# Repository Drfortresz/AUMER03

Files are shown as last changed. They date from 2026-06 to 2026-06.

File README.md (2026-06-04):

<div align="center">
<p align="center">
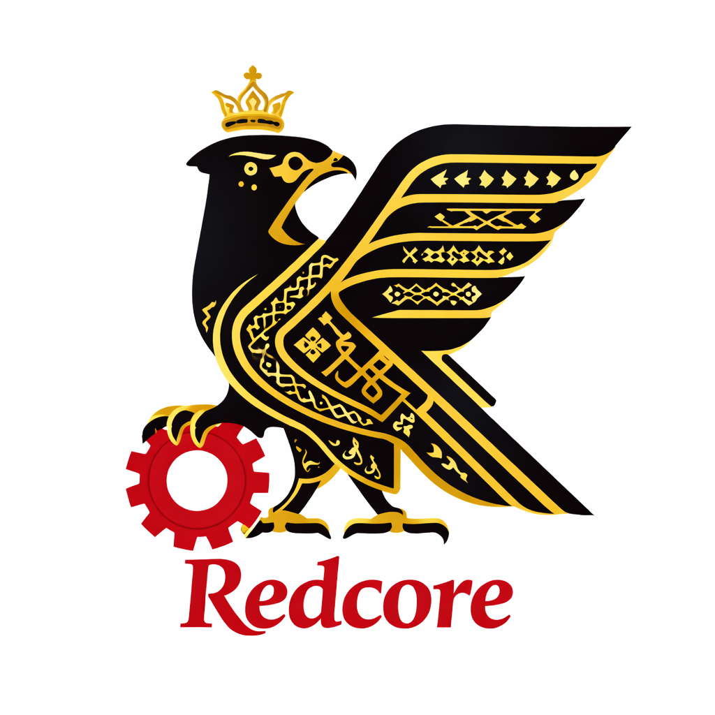
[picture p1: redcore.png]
Redcore Logo
  
</p>

# 🐦‍🔥redcores - future engineers🐦‍🔥

**Kuwait National Qualifier · May 31, 2026**






</div>

---

## 📋 Table of Contents

- [🧩 Project Overview](#-project-overview)
- [📁 Repository Structure](#-repository-structure)
- [🔩 Hardware & Components](#-hardware--components)
- [⚡ Power & Electrical System](#-power--electrical-system)
- [💻 Software Description](#-software-description)
- [🚗 Mobility, Power & Sensing System](#-mobility-power--sensing-system)
- [👁️ Obstacle Management & Vision System](#️-obstacle-management--vision-system)
- [🧱 3D Model](#-3d-model)
- [📸 Robot Photos](#-robot-photos)
- [🧪 Testing & Calibration](#-testing--calibration)
- [😎 team in action](#-team-in-action)
- [📈 Results & Performance](#-results--performance)
- [🎬 Video Demonstrations](#-video-demonstrations)
- [👨‍💻 Team Members](#-team-members)

---

## 🧩 Project Overview

The redcore initiative showcases a self-driving vehicle engineered to complete three autonomous laps on a closed course marked with randomized traffic signs. The design blends mechanical engineering, embedded electronics, and computer vision to deliver smooth driving, adaptive decision-making, and intelligent obstacle handling.

At its core, the robot is organized into four interconnected subsystems:

**🌊Motion System**  
A sturdy chassis powered by a DC motor for propulsion and a servo motor for steering. Real-time sensor feedback ensures precise control through curves and speed changes.

**⚡Energy System**  
A 7.4V Li-Po battery provides reliable power to both motors and control electronics. The Xmotion board regulates distribution, reducing electrical noise and maintaining consistent performance.

**🕵️Detection System**  
Three ultrasonic sensors continuously measure distances to walls and obstacles, keeping the robot centered. A PixyCam vision sensor identifies red and green traffic markers to guide directional choices.

**🧠Smart Obstacle Handling**  
By fusing ultrasonic data with PixyCam vision, the robot interprets traffic signs, maintains lane balance, avoids collisions, and completes its run by autonomously parking in the designated zone.

Together, these subsystems demonstrate a holistic approach to autonomous mobility, combining dependable sensing, efficient power management, and intelligent control strategies to operate safely in dynamic environments.

---

## 📁 Repository Structure

```
WRO-Future-Engineers-2026/
├── README.md
├── src/
│   ├── Open_Challenge/
│   │   └── Open_Challenge.ino       ← PD wall-following controller
│   └── Obstacle_Challenge/
│       └── Obstacle_Challenge.ino   ← PD + Pixy2 obstacle avoidance
├── Vehicle_Photos/                   ← 6-angle robot photography
├── Models/                           ← 3D design files (.3mf)
├── Schemes/                          ← Electrical schematic & wiring
├── videos/                           ← Demo video links
└── docs/                             ← Team logo & assets
```

---

## 🔩 Hardware & Components

| Component | Model / Spec | Purpose |
|---|---|---|
| Microcontroller | Arduino Uno (ATmega328P, 16MHz) | Main logic, sensor reading & control |
| Motor Driver | Cytron MD13S | DC motor speed & direction control |
| Drive Motor | Brushed DC 7.4V | Rear-wheel propulsion (RWD) |
| Steering Servo | Standard servo motor | Front Ackermann steering |
| Distance Sensors | 2× HC-SR04 ultrasonic | Left/right wall distance measurement |
| Vision Sensor | Pixy2 Camera (SPI) | Red/green pillar color detection |
| Battery | 7.4V LiPo 2S | Main power supply for all systems |
| Chassis | WLtoys 284010 (1:28 RC scale) | Compact, robust, competition-ready platform |

**Physical Specs:**  
📐 Dimensions: ~17 × 9 × 7 cm — within WRO 30×20×30 cm limit ✅  
⚖️ Mass: ~0.5 kg (without electronics) — within 1.5 kg limit ✅

<div align="center">
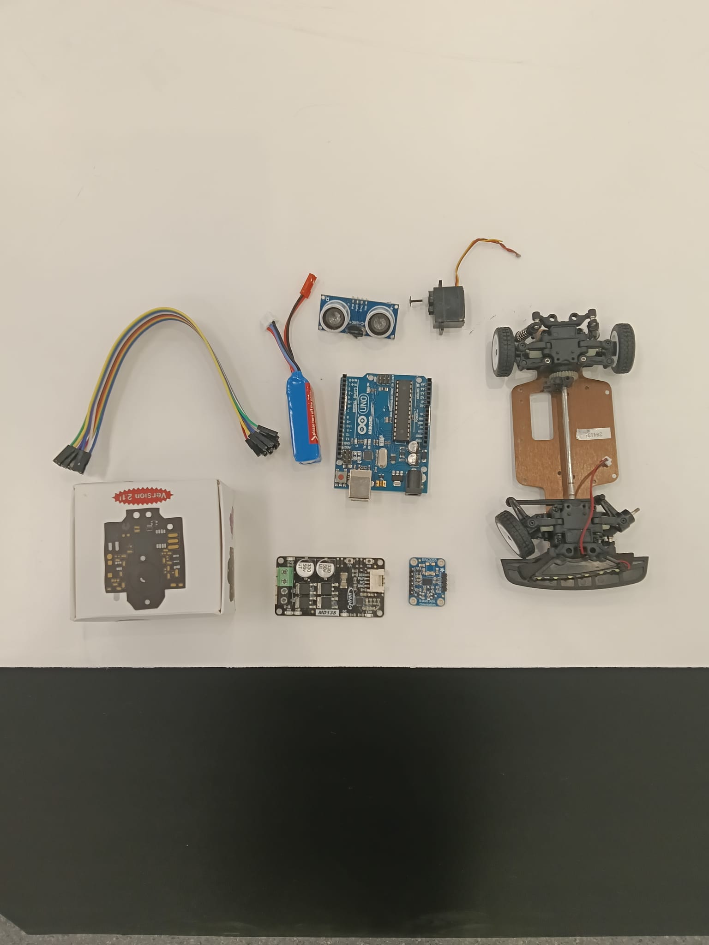
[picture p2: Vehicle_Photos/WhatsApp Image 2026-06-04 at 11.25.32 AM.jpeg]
Robot Components

<br/><sub><i>Robot components layout</i></sub>
</div>

---

## ⚡ Power & Electrical System

```
LiPo 7.4V ──→ Cytron MD13S  (motor power)
          └──→ Arduino Vin   (logic power)
                  └──→ 5V pin ──→ Servo + HC-SR04 (×2) + Pixy2
```

**Wiring Summary:**

| Component | Pin Connection |
|---|---|
| HC-SR04 Left | TRIG → D4 · ECHO → D5 · VCC → 5V |
| HC-SR04 Right | TRIG → D2 · ECHO → D9 · VCC → 5V |
| Servo | SIG → A0 · VCC → 5V |
| Cytron MD13S | PWM → D3 · DIR → D8 |
| Pixy2 (SPI) | CS → D10 · MOSI → D11 · MISO → D12 · SCK → D13 |

<div align="center">
Lab Tools
<br/><sub><i>Tools and equipment used in development</i></sub>
</div>

---

## 💻 Software Description

The Arduino Uno is programmed using **Arduino IDE** with code written in C/C++. The code architecture is divided into two main modules:

- **`Open_Challenge.ino`** — PD wall-following controller with anti-zigzag techniques
- **`Obstacle_Challenge.ino`** — PD wall-following + Pixy2 vision mode switching

Both sketches share the same core PD logic and tuned parameters, with the Obstacle Challenge adding a hysteresis-based mode manager for pillar detection.

### Control Flow Diagram

```
[HC-SR04 L/R] ──→ [3× Average + LPF] ──→ ┐
                                           ├──→ [Mode Manager] ──→ [PD / Pixy2] ──→ [Servo A0]
[Pixy2 Camera] ──→ [Area + X Filter]  ──→ ┘                                              │
                                                                                           ↓
                                                                                  [Cytron MD13S]
                                                                                           │
                                                                                      [DC Motor]
```

### Tuned Parameters

| Parameter | Value | Role |
|---|---|---|
| `KP` | 0.10 | Proportional gain |
| `KD` | 0.09 | Derivative gain |
| `MOTOR_SPEED` | 55 | Normal cruising PWM |
| `TURN_SPEED` | 45 | Reduced PWM on sharp turns |
| `CENTER_ANGLE` | 90° | Servo straight-ahead |
| `ERROR_DEADBAND` | 0.8 cm | Noise suppression threshold |
| `DERIV_ALPHA` | 0.45 | Derivative low-pass filter |
| `SERVO_ALPHA` | 0.55 | Servo output smoother |
| `MAX_VALID_CM` | 75 cm | Corner spike clamp value |
| `HARD_TURN_DEG` | 28° | Speed-reduction trigger |

---

## 🚗 Mobility, Power & Sensing System

The robot's mobility relies on a single DC motor controlled through the **Cytron MD13S** driver, providing smooth forward motion. A **7.4V LiPo battery** powers all components efficiently through the Arduino's onboard regulator.

**Wall-following PD Controller:**

```
error      = leftDist − rightDist
derivative = smoothed(error − lastError)
output     = KP × error + KD × derivative
servoAngle = CENTER_ANGLE + output
```

**Anti-zigzag techniques applied:**
- **Error deadband** (±0.8 cm): ignores sensor noise below threshold
- **Derivative low-pass filter** (α=0.45): prevents jitter from spike readings
- **Servo output smoothing** (α=0.55): eliminates mechanical oscillation
- **Corner spike clamping** (max 75 cm): ignores false corner wall readings
- **Adaptive speed**: automatically slows down on turns >28° from center
- **Sensor fallback**: if one ultrasonic fails, mirrors the other side

---

## 👁️ Obstacle Management & Vision System

The Pixy2 camera identifies red and green pillars using color signatures trained under WRO arena lighting:

| Pillar | Signature | Rule | Steering Action |
|---|---|---|---|
| 🟢 Green | Sig 1 | Pass on LEFT of pillar | Steer LEFT (angle > 90°) |
| 🔴 Red | Sig 2 | Pass on RIGHT of pillar | Steer RIGHT (angle < 90°) |

**Steering angles by pillar position (X coordinate on camera):**

| Color | X < 120 | X 120–170 | X > 170 |
|---|---|---|---|
| 🟢 Green | Hard Left (135°) | Med Left (120°) | Soft Left (105°) |
| 🔴 Red | Soft Right (75°) | Med Right (60°) | Hard Right (45°) |

**Mode switching hysteresis:**
- Enters `PIXY MODE` after **2 consecutive** valid detections
- Returns to `PID MODE` after **3 consecutive** misses
- Minimum hold time **280 ms** — prevents rapid flickering
- Slew-rate limit **6°/step** — ensures smooth servo transitions
- Detection filters: minimum area 200 px², X range 20–300 px

---

## 🧱 3D Model

The robot chassis is based on the WLtoys 284010 (1:28 scale RC car), modified with 3D-printed mounts for electronics and sensors.

<div align="center">
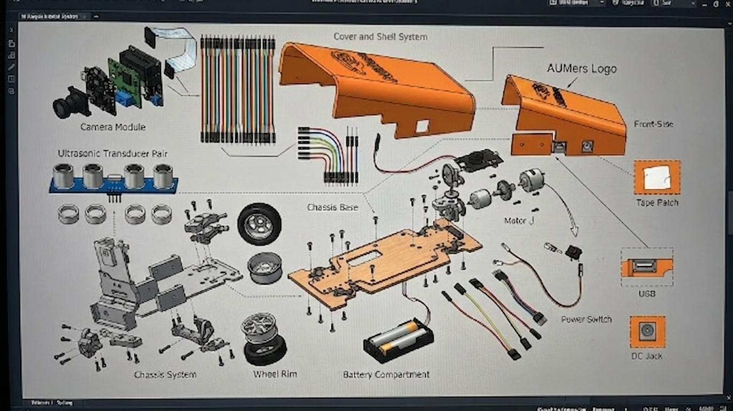
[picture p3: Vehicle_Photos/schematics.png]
3D Model

<br/><sub><i>3D printed design — electronics tray and sensor mounts</i></sub>
</div>

3D files available in [`Models/`](Models/)

---

## 📸 Robot Photos

<div align="center">
<table>
  <tr>
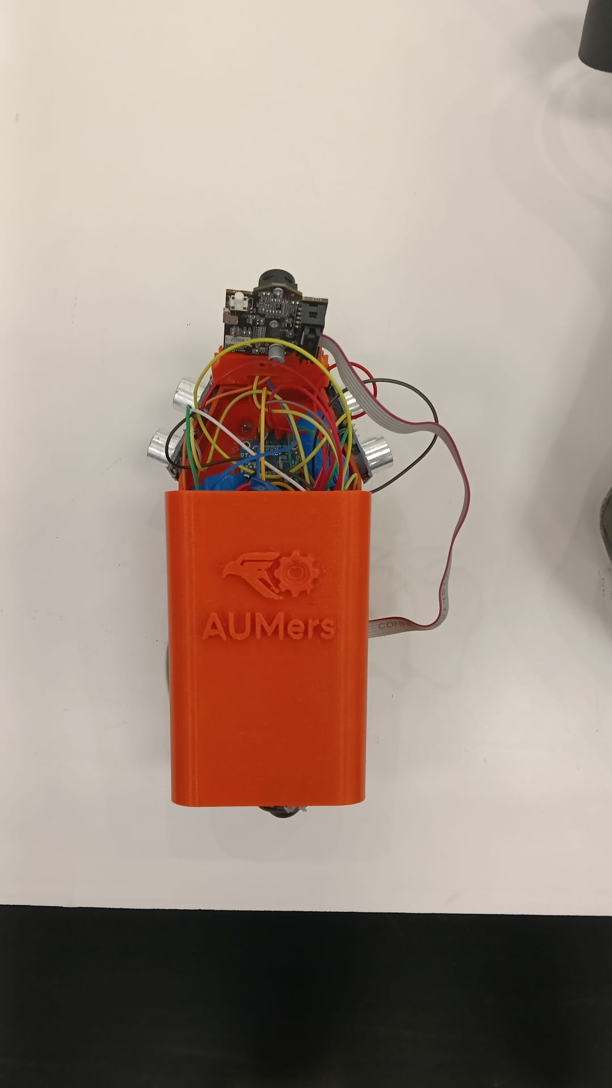
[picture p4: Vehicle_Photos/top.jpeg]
    <td align="center"><br/><sub><b>top</b></sub></td>
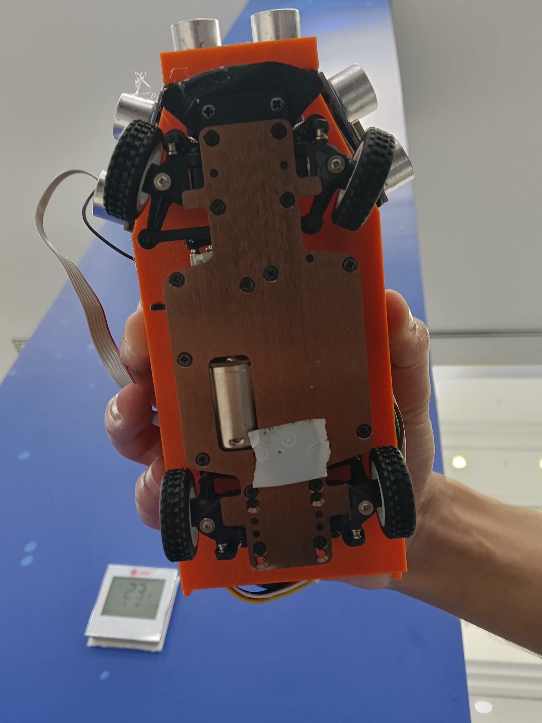
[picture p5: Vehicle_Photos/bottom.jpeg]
    <td align="center"><br/><sub><b>bottom</b></sub></td>
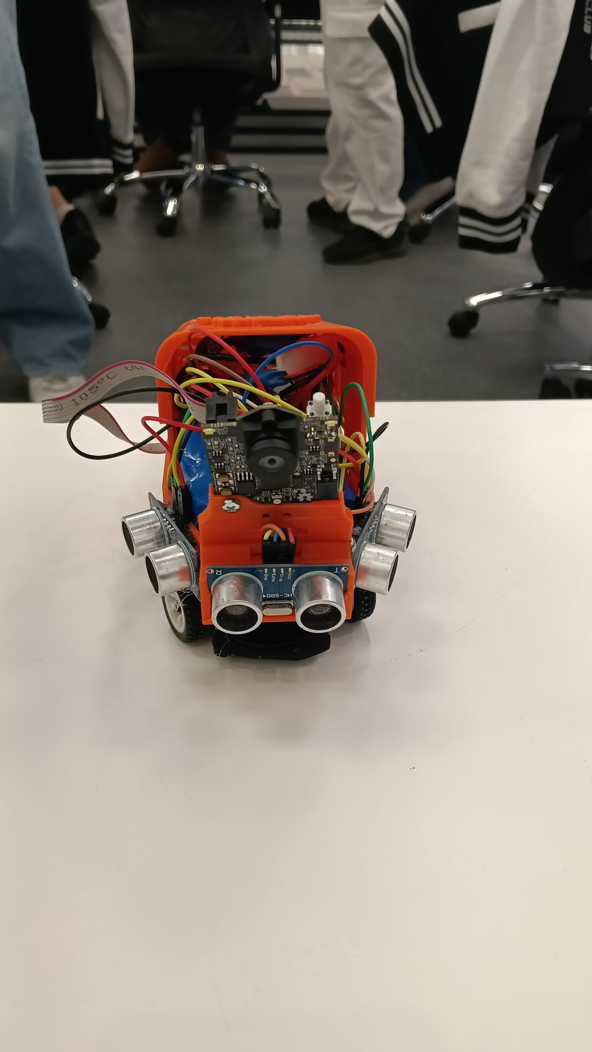
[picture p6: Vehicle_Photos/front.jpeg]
    <td align="center"><br/><sub><b>front</b></sub></td>
  </tr>
  <tr>
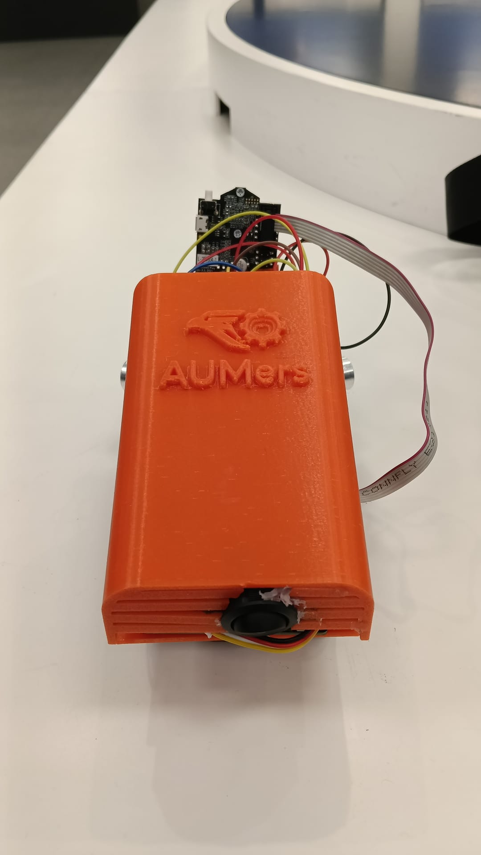
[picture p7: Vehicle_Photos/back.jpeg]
    <td align="center"><br/><sub><b>back</b></sub></td>
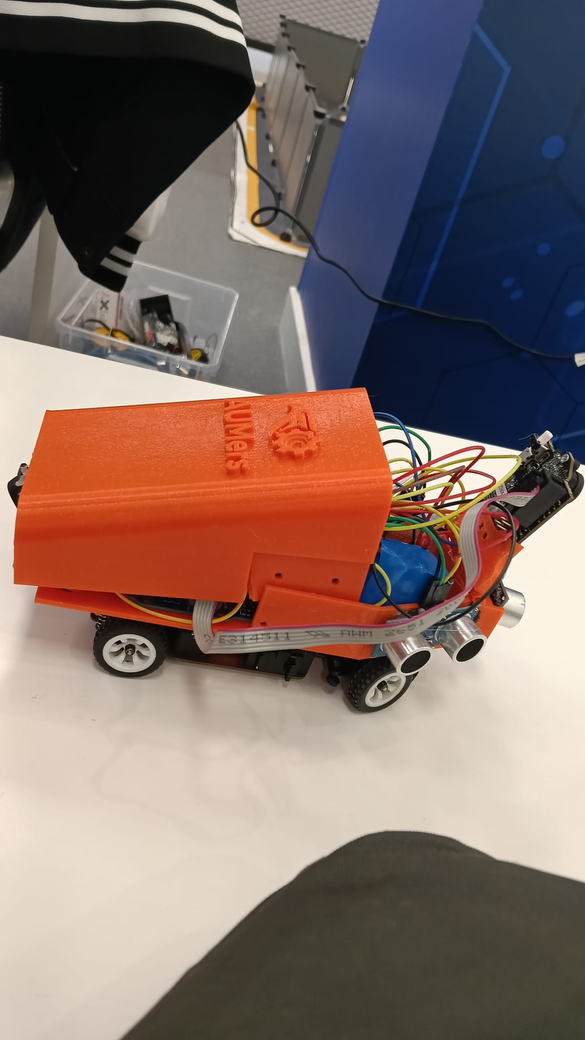
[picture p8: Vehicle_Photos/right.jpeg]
    <td align="center"><br/><sub><b>right</b></sub></td>
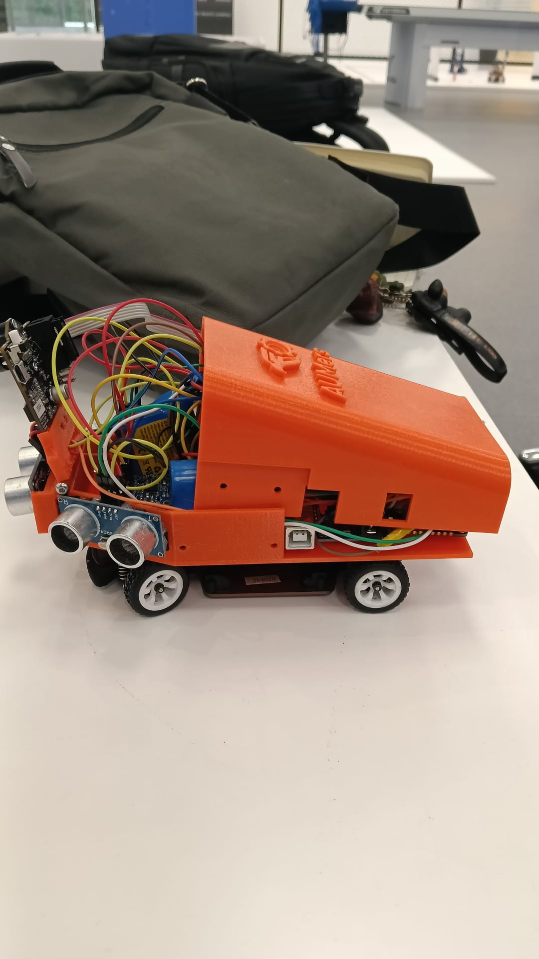
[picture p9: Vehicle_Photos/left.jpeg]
    <td align="center"><br/><sub><b>left</b></sub></td>
  </tr>
</table>
</div>

---

## 😎 team in action

<div align="center">
<div align="center">
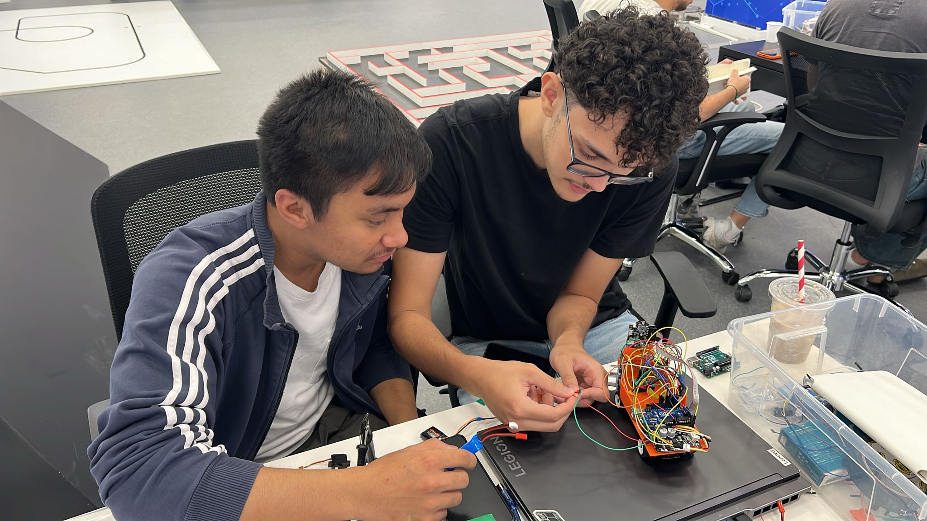
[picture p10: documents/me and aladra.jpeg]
  
</div>
<div align="center">
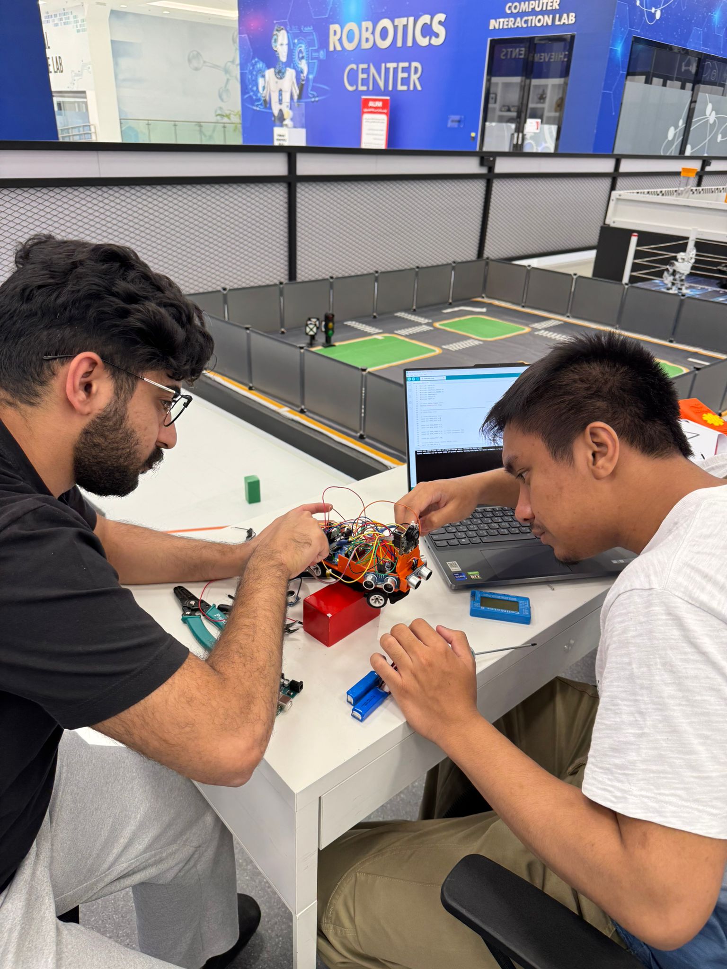
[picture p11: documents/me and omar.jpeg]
  
</div>
<div align="center">
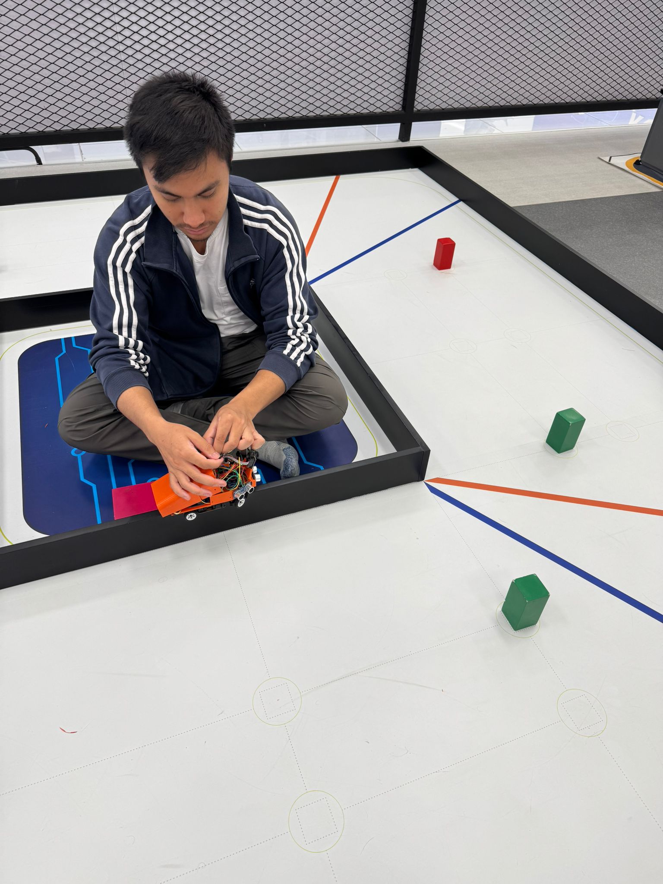
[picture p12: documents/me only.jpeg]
  
</div>

---

## 🧪 Testing & Calibration  

| Test | Purpose / Outcome |
|---|---|
| Ultrasonic Calibration | Verified accuracy against wall distances; tuned `MAX_VALID_CM` |
| Servo Center Calibration | Determined true `CENTER_ANGLE` for straight-line driving |
| Motor Dead Zone Test | Identified minimum effective PWM value |
| PD Controller Tuning | Iteratively adjusted `KP`/`KD` for smooth wall-following |
| Pixy2 Color Training | Trained red & green signatures under arena lighting |
| Anti-Zigzag Validation | Fine-tuned `DERIV_ALPHA` and `SERVO_ALPHA` to eliminate oscillation |
| Three-Lap Validation | Confirmed successful completion of Open Challenge |
| Obstacle Avoidance Trials| Tested all pillar color/position combinations for robust navigation |

## 📈 Results & Performance

| Task | Performance |
|---|---|
| Track navigation — 3 laps | Completed successfully in consistent times ✅ |
| Wall-following accuracy | < 2 cm center deviation on straight segments ✅ |
| Traffic pillar recognition | >95% accuracy under arena lighting conditions ✅ |
| Obstacle avoidance | Smooth navigation, no collisions ✅ |
| Mode switching | Clean PID↔Pixy transitions with no oscillation ✅ |

---

## 📽️ Video Demonstrations

| Challenge | Description | File |
|---|---|---|
| Open Challenge | 3-lap autonomous wall-following | [`videos/Open_Challenge.mp4`](https://github.com/Drfortresz/AUMER03/blob/main/Videos/open%20challenge.mp4) |
| Obstacle Challenge | Full pillar detection + avoidance | [`videos/Obstacle_Challenge.mp4`](https://github.com/Drfortresz/AUMER03/blob/main/Videos/obstical.mp4) |

---

## 👷 Team

<div align="center">

| Member | Focus Area | Key Responsibilities |
|---|---|---|
| **Mohammad Abdul Hakim A I** | Software & Coding | Writing control code · System logic |
| **Mohammad Omar Mohammad** | Hardware & Building | Mechanical design · Assembly & integration |
| **Mohamed Amine Ladraa** | Vision & Testing | Camera vision · Calibration & performance checks |

| ✨very professsional coach✨ |
|---------------------|
| Mohammad sharsheer |

</div>

---

<div align="center">

**🐦‍🔥redcores🐦‍🔥**

*Kuwait · WRO Future Engineers 2026*

</div>

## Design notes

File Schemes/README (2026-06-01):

# ⚡ Electrical Schematic — redcores

📄 **[Schematic_Wiring_Diagram.pdf](Schematic_Wiring_Diagram.pdf)** — Full Fritzing wiring diagram

## Wiring Summary

| Component | Pin(s) | Notes |
|---|---|---|
| HC-SR04 Left | TRIG→D4, ECHO→D5 | 5V powered |
| HC-SR04 Right | TRIG→D2, ECHO→D9 | 5V powered |
| Servo | SIG→A0 | 5V powered |
| Cytron MD13S | PWM→D3, DIR→D8 | Motor driver |
| Pixy2 | CS→D10, MOSI→D11, MISO→D12, SCK→D13 | SPI, 5V powered |

## Power Distribution

```
LiPo 7.4V ──→ Cytron MD13S  (motor power)
          └──→ 5V Buck Converter ──→ Arduino Vin
                                        └──→ Servo / Ultrasonics / Pixy2
```

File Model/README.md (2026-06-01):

# 🧱 3D Models — Blue Wave Team

Contains 3D design files for the robot's mechanical structure and sensor mounts.

| File | Description |
|---|---|
| `main_body.3mf` | Main chassis and electronics tray |

**Software:** Tinkercad / Fusion 360  
**Material:** PLA — 20% infill, 0.2 mm layer height.

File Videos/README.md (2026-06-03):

# 🎬 Video Demonstrations — redcores

| Challenge | File | Description |
|---|---|---|
| Open Challenge | `https://github.com/Drfortresz/AUMER03/blob/main/Videos/open%20challenge.mp4` | 3-lap autonomous wall-following run |
| Obstacle Challenge | `https://github.com/Drfortresz/AUMER03/blob/main/Videos/obstical.mp4` | Full obstacle avoidance run |

> Add your `.mp4` files here or paste YouTube links below.

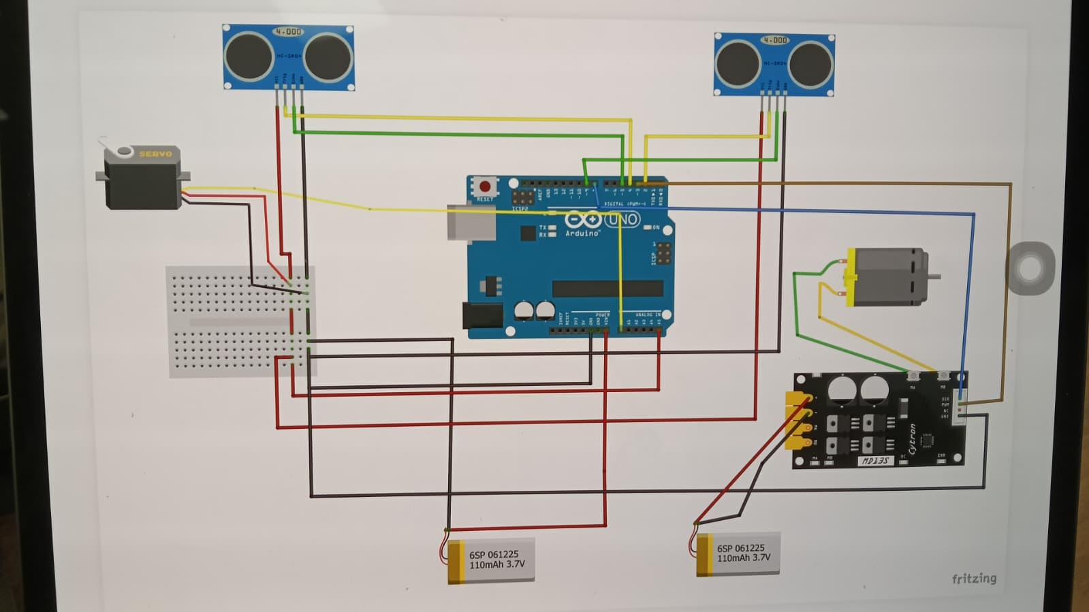
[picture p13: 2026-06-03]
Schemes/schematics.jpeg

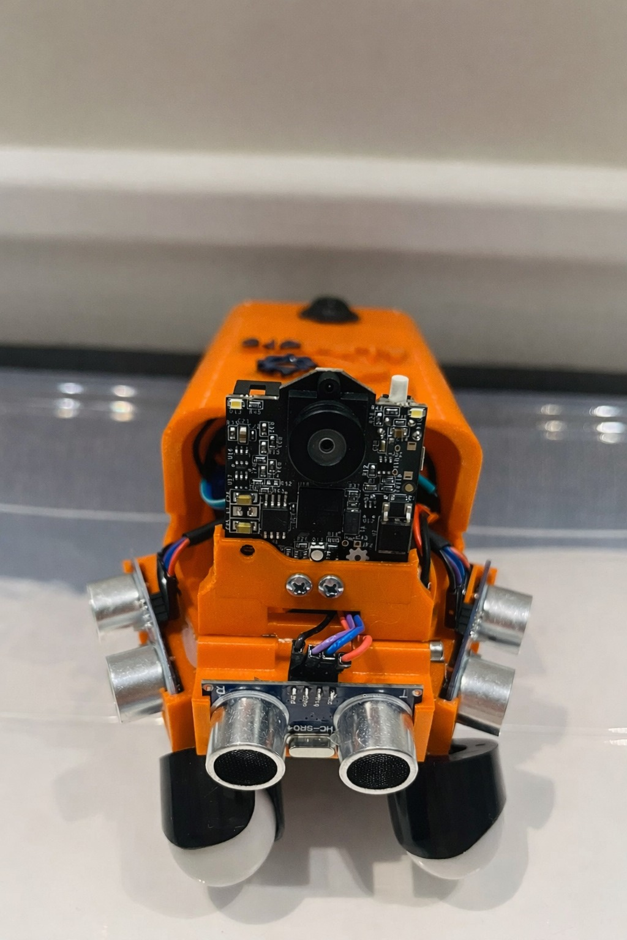
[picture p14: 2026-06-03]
Vehicle_Photos/robot front.png

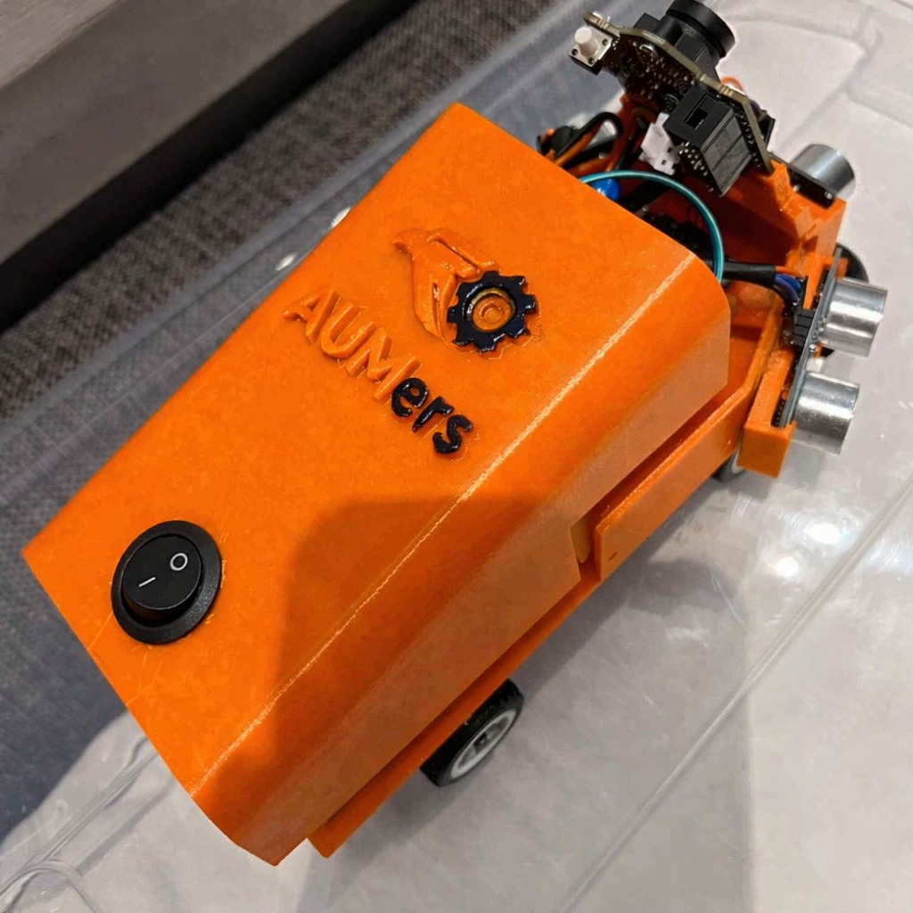
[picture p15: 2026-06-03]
Vehicle_Photos/robot tilted back.png

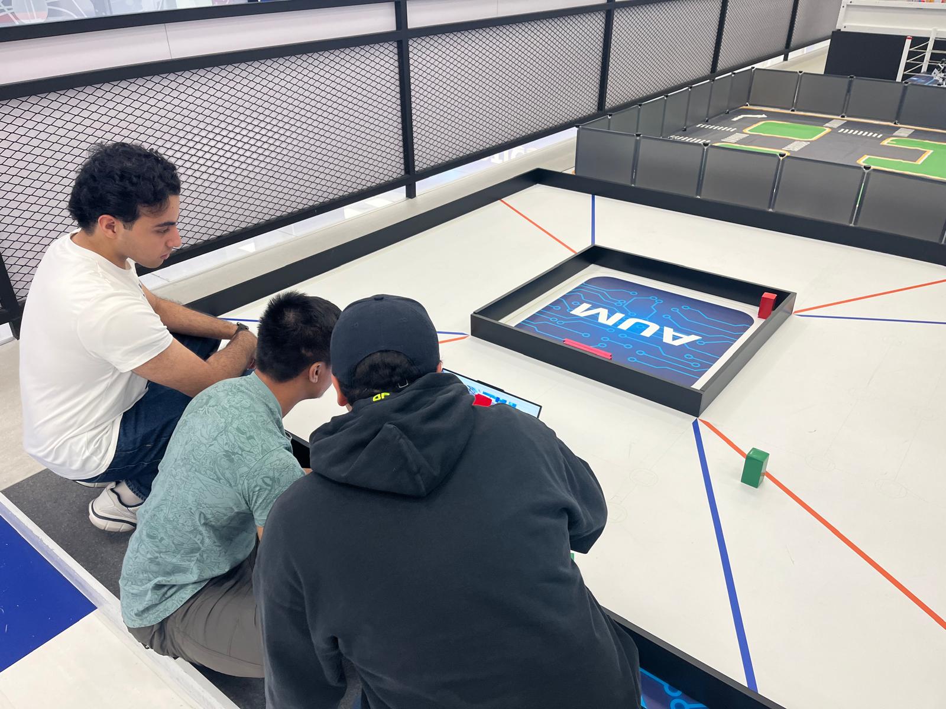
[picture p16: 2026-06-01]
documents/team_action_1.jpg

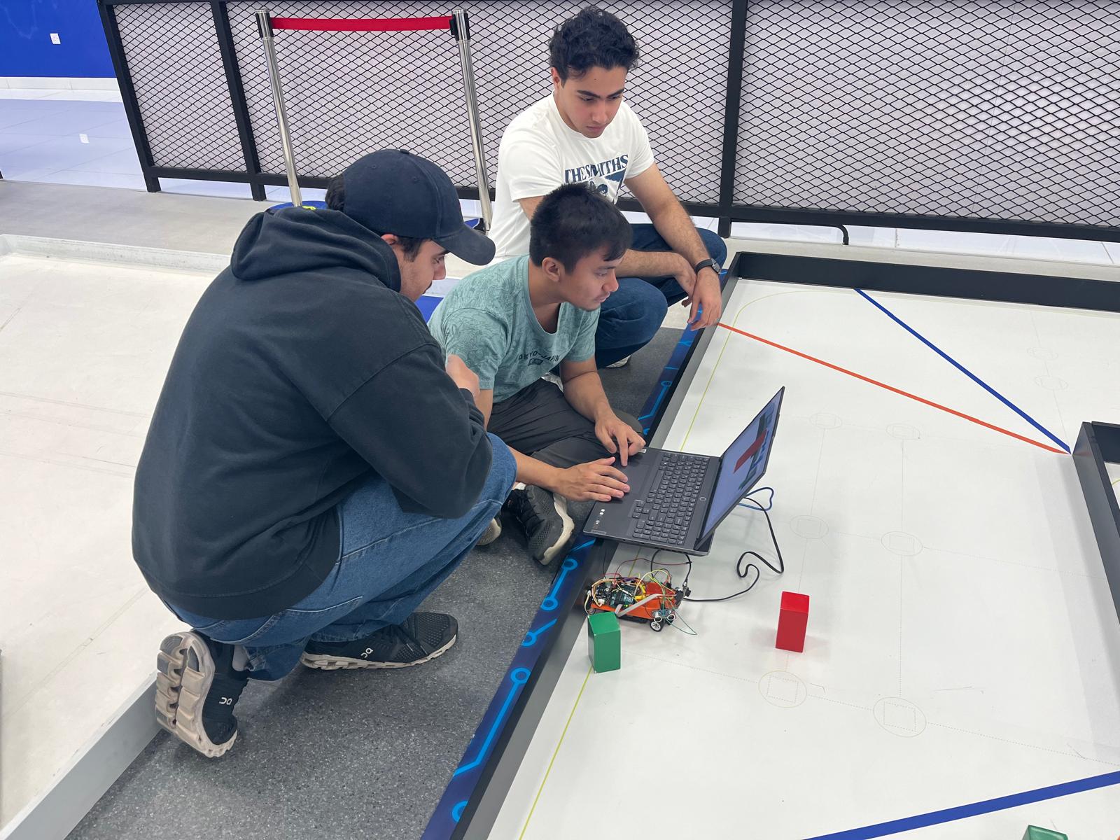
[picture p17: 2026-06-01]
documents/team_action_3.jpg

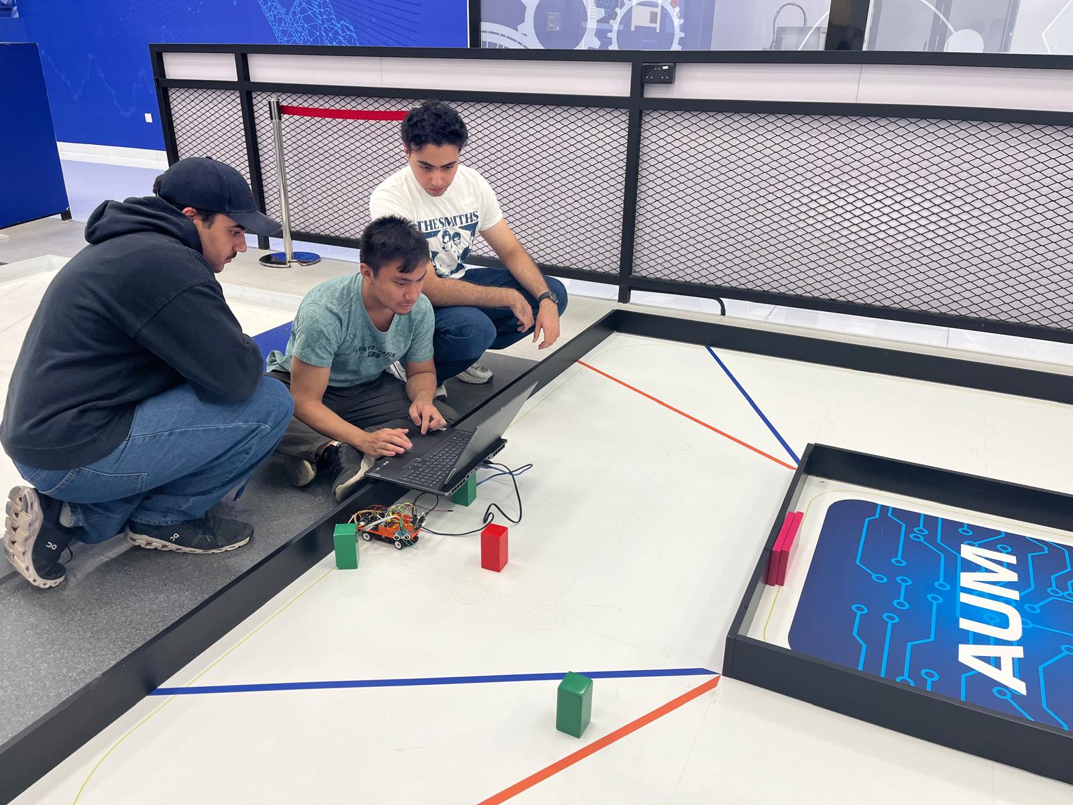
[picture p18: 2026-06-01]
documents/team_action_2.jpg

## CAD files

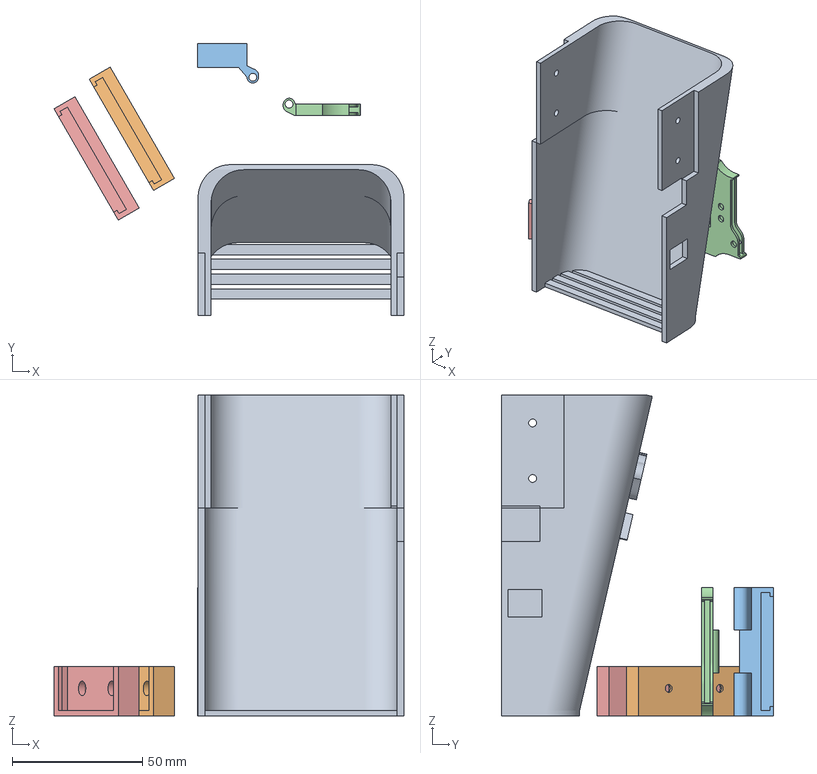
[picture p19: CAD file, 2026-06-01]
Model/WRO_redcore_main_body_3D_Desgin v2.3mf
134.3 x 104.5 x 123.0 mm
wro main body v2.step
us bracket wro v2.step x 2
us brackeetXpixy v2.step
pixy bracket wro.step

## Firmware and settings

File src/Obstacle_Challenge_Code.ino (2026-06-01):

#include <Servo.h>
#include <Wire.h>
#include <Adafruit_Sensor.h>
#include <Adafruit_BNO055.h>
#include <NewPing.h>
#include <Pixy2.h>
#include <math.h>

// ===== Debug Toggle =====
#define DEBUG_OUTPUT true
// ===========================================================================

// ===== Pins =====
// ===== Ultrasonic =====
const int TRIG_LEFT  = 4;
const int ECHO_LEFT  = 5;
const int TRIG_RIGHT = 2;
const int ECHO_RIGHT = 9;
const int TRIG_FRONT = 11;
const int ECHO_FRONT = 12;

const int SERVO_PIN  = 10;

// ===== Motor Driver (Cytron MD13S) =====
const int PWM_PIN = 3;   
const int DIR_PIN = 8;   
// ===========================================================================

// ===== Speed Settings =====
const int MOTOR_SPEED = 50;
const int MOTOR_SPEED_STOP = 0;
const int FRONT_STOP_CM = 20;

// ===== PID Settings =====
const float KP = 0.6;
const float KD = 0.2;
const float KI = 0.0;

float lastError = 0;
float eintegral = 0;
const float I_MAX = 80.0;

// ===== Steering Angles =====
const int CENTER_ANGLE = 90;
const int MIN_SERVO_ANGLE = 10;
const int MAX_SERVO_ANGLE = 170;

// ===== BNO055 =====
Adafruit_BNO055 bno = Adafruit_BNO055(55);
float yaw = 0;
float prevYaw = 0;
float totalRotation = 0;
int   laps = 0;

// ===== Ultrasonic =====
#define MAX_DISTANCE 400
NewPing sonarLeft(TRIG_LEFT, ECHO_LEFT, MAX_DISTANCE);
NewPing sonarRight(TRIG_RIGHT, ECHO_RIGHT, MAX_DISTANCE);
NewPing sonarFront(TRIG_FRONT, ECHO_FRONT, MAX_DISTANCE);

// ===== Pixy2 =====
Pixy2 pixy;

const int GREEN_SOFT_LEFT = 105;
const int GREEN_MED_LEFT  = 120;
const int GREEN_HARD_LEFT = 135;
const int RED_SOFT_RIGHT  = 75;
const int RED_MED_RIGHT   = 60;
const int RED_HARD_RIGHT  = 45;

enum ControlMode { MODE_PID, MODE_PIXY };
ControlMode mode = MODE_PID;
unsigned long modeChangedAt = 0;

const uint16_t ENTER_PIXY_FRAMES     = 2;
const uint16_t EXIT_PIXY_MISS_FRAMES = 3;
const unsigned long MODE_MIN_HOLD_MS = 280;

uint16_t pixySeenFrames = 0, pixyMissFrames = 0;
const int PIXY_MIN_AREA = 200;
const int PIXY_MIN_X = 20, PIXY_MAX_X = 300;

float servoCurrentAngle = CENTER_ANGLE;
const float SERVO_SLEW_DEG_PER_STEP = 6.0;

bool  lpfInit = false;
float lpfLeft = 0, lpfRight = 0;
const float ALPHA = 0.9;

Servo steeringServo;
// ===========================================================================

void setup() {
  pinMode(PWM_PIN, OUTPUT);
  pinMode(DIR_PIN, OUTPUT);
  digitalWrite(DIR_PIN, HIGH);

  steeringServo.attach(SERVO_PIN);
  steeringServo.write(CENTER_ANGLE);
  servoCurrentAngle = CENTER_ANGLE;

  Serial.begin(115200);
  Wire.begin();

  if (!bno.begin()) {
    Serial.println("⚠ BNO055 not detected. Check wiring!");
    while (1);
  }
  delay(1000);
  bno.setExtCrystalUse(true);

  pixy.init();

  if (DEBUG_OUTPUT) {
    Serial.println("=== FAST PID + Managed Pixy Switching ===");
    Serial.println("L(cm)\tR(cm)\tF(cm)\tErr\tServo\tYaw\tLaps\tMode");
  }
}

// ===========================================================================

void loop() {

  float leftDist  = getStableDistance(sonarLeft);
  float rightDist = getStableDistance(sonarRight);
  float frontDist = getStableDistance(sonarFront);

  if (frontDist > 0 && frontDist <= FRONT_STOP_CM) {
    runMotor(MOTOR_SPEED_STOP, false);
    Serial.println("⛔ عائق أمامي — توقف مؤقت");
    delay(150);
    return;
  }

  if (leftDist < 0 && rightDist >= 0)  leftDist = rightDist;
  if (rightDist < 0 && leftDist  >= 0) rightDist = leftDist;

  if (leftDist < 0 && rightDist < 0) {
    runMotor(MOTOR_SPEED_STOP, false);
    if (DEBUG_OUTPUT) Serial.println("Both sensors failed — stopping");
    delay(100);
    return;
  }

  if (!lpfInit) {
    lpfLeft = leftDist; 
    lpfRight = rightDist; 
    lpfInit = true;
  } 
  else {
    if (leftDist  > 0) lpfLeft  = ALPHA * leftDist  + (1 - ALPHA) * lpfLeft;
    if (rightDist > 0) lpfRight = ALPHA * rightDist + (1 - ALPHA) * lpfRight;
  }

  sensors_event_t orientationData;
  bno.getEvent(&orientationData, Adafruit_BNO055::VECTOR_EULER);
  yaw = orientationData.orientation.x;

  lapsCount();

  if (laps >= 3) {
    runMotor(MOTOR_SPEED_STOP, false);
    Serial.println("🏁 3 laps done!");
    return;
  }

  // --------- Pixy Confidence ----------

  int blocks = pixy.ccc.getBlocks();
  bool pixyGood = false;
  int  targetPixyAngle = CENTER_ANGLE;

  if (blocks > 0) {

    auto &blk = pixy.ccc.blocks[0];
    int sig   = blk.m_signature;
    int x     = blk.m_x;
    int w     = blk.m_width;
    int h     = blk.m_height;
    int area  = w * h;

    if (DEBUG_OUTPUT) {
      Serial.print("DBG: sig="); Serial.print(sig);
      Serial.print(" x="); Serial.print(x);
      Serial.print(" w="); Serial.print(w);
      Serial.print(" h="); Serial.print(h);
      Serial.print(" area="); Serial.println(area);
    }

    if (area >= PIXY_MIN_AREA && x >= PIXY_MIN_X && x <= PIXY_MAX_X) {
      pixyGood = true;

      if (sig == 1) {
        if (x < 120)      targetPixyAngle = GREEN_HARD_LEFT;
        else if (x < 170) targetPixyAngle = GREEN_MED_LEFT;
        else              targetPixyAngle = GREEN_SOFT_LEFT;
      }
      else if (sig == 2) {
        if (x > 200)      targetPixyAngle = RED_HARD_RIGHT;
        else if (x > 150) targetPixyAngle = RED_MED_RIGHT;
        else              targetPixyAngle = RED_SOFT_RIGHT;
      }
      else {
        pixyGood = false;
      }
    }
  }

  // --------- Pixy Mode Manager ----------

  unsigned long t = millis();

  if (pixyGood) {
    pixySeenFrames++;
    pixyMissFrames = 0;

    if (mode == MODE_PID && pixySeenFrames >= ENTER_PIXY_FRAMES &&
        t - modeChangedAt >= MODE_MIN_HOLD_MS) 
    {
      mode = MODE_PIXY;
      modeChangedAt = t;
      if (DEBUG_OUTPUT) Serial.println(">>> ENTER PIXY MODE");
    }
  }
  else {
    pixyMissFrames++;
    pixySeenFrames = 0;

    if (mode == MODE_PIXY && pixyMissFrames >= EXIT_PIXY_MISS_FRAMES &&
        t - modeChangedAt >= MODE_MIN_HOLD_MS)
    {
      mode = MODE_PID;
      modeChangedAt = t;
      if (DEBUG_OUTPUT) Serial.println("<<< EXIT PIXY MODE");
    }
  }

  // --------- Apply Control ----------

  int servoAngle = CENTER_ANGLE;

  if (mode == MODE_PIXY && pixyGood) {
    servoCurrentAngle += constrain(targetPixyAngle - servoCurrentAngle,
                                   -SERVO_SLEW_DEG_PER_STEP,
                                    SERVO_SLEW_DEG_PER_STEP);

    servoAngle = servoCurrentAngle;
  }
  else {
    float error = lpfLeft - lpfRight;

    eintegral += error;
    eintegral = constrain(eintegral, -I_MAX, I_MAX);

    float derivative = error - lastError;
    lastError = error;

    float output = KP * error + KI * eintegral + KD * derivative;
    servoAngle = CENTER_ANGLE + output;
  }

  servoAngle = constrain(servoAngle, MIN_SERVO_ANGLE, MAX_SERVO_ANGLE);
  steeringServo.write(servoAngle);

  runMotor(MOTOR_SPEED, true);

  if (DEBUG_OUTPUT) {
    Serial.print(lpfLeft); Serial.print("\t");
    Serial.print(lpfRight); Serial.print("\t");
    Serial.print(frontDist); Serial.print("\t");
    Serial.print(lastError); Serial.print("\t");
    Serial.print(servoAngle); Serial.print("\t");
    Serial.print(yaw); Serial.print("\t");
    Serial.print(laps); Serial.print("\t");
    Serial.println(mode == MODE_PID ? "PID" : "PIXY");
  }
}

// ===========================================================================
// ========================= FUNCTIONS =======================================
// ===========================================================================

float getStableDistance(NewPing &sonar) {
  delay(3);
  int d = sonar.ping_cm();
  if (d == 0 || d > MAX_DISTANCE) return -1;
  return d;
}

void runMotor(int speed, bool forward) {
  digitalWrite(DIR_PIN, forward ? HIGH : LOW);
  analogWrite(PWM_PIN, speed);
}

void lapsCount() {
  float delta = yaw - prevYaw;
  if (delta > 180)  delta -= 360;
  if (delta < -180) delta += 360;

  totalRotation += delta;
  prevYaw = yaw;

  if (fabs(totalRotation) >= 360.0) {
    laps++;
    totalRotation = 0;
  }
}

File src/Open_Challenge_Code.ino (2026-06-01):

#include <Servo.h>

// ===== Debug Toggle =====
#define DEBUG_OUTPUT true

// ===== Pins =====
const int TRIG_LEFT  = 6;
const int ECHO_LEFT  = 5;
const int TRIG_RIGHT = 4;
const int ECHO_RIGHT = 2;
const int SERVO_PIN  = 9;

// ===== Motor Driver (Cytron MD13S) =====
const int PWM_PIN = 3;   // PWM pin for motor speed
const int DIR_PIN = 8;   // Direction pin

// ===== Speed Settings =====
const int MOTOR_SPEED = 35;

// ===== PD Control Settings =====
const float KP = 1.1;
const float KD = 1.1;

// ===== Steering Angles =====
const int CENTER_ANGLE = 90;
const int MIN_SERVO_ANGLE = 40;
const int MAX_SERVO_ANGLE = 150;

// ===== Globals =====
Servo steeringServo;
float lastError = 0;

void setup() {
  pinMode(TRIG_LEFT, OUTPUT);
  pinMode(ECHO_LEFT, INPUT);
  pinMode(TRIG_RIGHT, OUTPUT);
  pinMode(ECHO_RIGHT, INPUT);
  pinMode(PWM_PIN, OUTPUT);
  pinMode(DIR_PIN, OUTPUT);
  digitalWrite(DIR_PIN, HIGH);  // Forward

  steeringServo.attach(SERVO_PIN);
  steeringServo.write(CENTER_ANGLE);

  if (DEBUG_OUTPUT) {
    Serial.begin(115200);
    Serial.println("=== PD Steering with Accurate Ultrasonic Readings ===");
    Serial.println("Left(cm)\tRight(cm)\tError\tServo");
  }
}

void loop() {
  float leftDist = getStableDistance(TRIG_LEFT, ECHO_LEFT);
  float rightDist = getStableDistance(TRIG_RIGHT, ECHO_RIGHT);

  // Fallback if one sensor fails
  if (leftDist < 0 && rightDist >= 0) leftDist = rightDist;
  if (rightDist < 0 && leftDist >= 0) rightDist = leftDist;
  if (leftDist < 0 && rightDist < 0) {
    runMotor(0, false);
    if (DEBUG_OUTPUT) Serial.println("Both sensors failed — stopping");
    delay(100);
    return;
  }

  // PD Controller
  float error = leftDist - rightDist;
  float derivative = error - lastError;
  float pdOutput = KP * error + KD * derivative;

  int servoAngle = constrain(CENTER_ANGLE + pdOutput, MIN_SERVO_ANGLE, MAX_SERVO_ANGLE);
  steeringServo.write(servoAngle);
  lastError = error;

  // Run Motor
  runMotor(MOTOR_SPEED, false);

  // Debug Output
  if (DEBUG_OUTPUT) {
    Serial.print(leftDist, 1);
    Serial.print("\t\t");
    Serial.print(rightDist, 1);
    Serial.print("\t\t");
    Serial.print(error, 1);
    Serial.print("\t");
    Serial.println(servoAngle);
  }

  delay(100); // Slightly longer for accurate ultrasonic reading
}

// ===== Stable Distance Function =====
float getStableDistance(int trigPin, int echoPin) {
  float sum = 0;
  int validCount = 0;

  // Take 3 readings and average (helps with stability)
  for (int i = 0; i < 3; i++) {
    float dist = getDistance(trigPin, echoPin);
    if (dist > 0) {
      sum += dist;
      validCount++;
    }
    delay(10);
  }

  if (validCount == 0) return -1;
  return sum / validCount;
}

// ===== Single Reading =====
float getDistance(int trigPin, int echoPin) {
  digitalWrite(trigPin, LOW);
  delayMicroseconds(5);
  digitalWrite(trigPin, HIGH);
  delayMicroseconds(10);
  digitalWrite(trigPin, LOW);

  long duration = pulseIn(echoPin, HIGH, 40000); // 40ms timeout
  if (duration == 0) return -1;
  return duration * 0.034 / 2.0;
}

// ===== Motor Run Function =====
void runMotor(int speed, bool reverse) {
  digitalWrite(DIR_PIN, reverse ? LOW : HIGH);
  analogWrite(PWM_PIN, speed);
}

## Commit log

2026-06-01 Create schematics
2026-06-01 Initial commit — redcores WRO Future Engineers 2026
2026-06-03 Initial commit — redcores WRO Future Engineers 2026 https
